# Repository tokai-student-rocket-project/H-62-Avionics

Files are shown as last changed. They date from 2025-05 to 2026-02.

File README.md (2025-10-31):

# H-62-Avionics

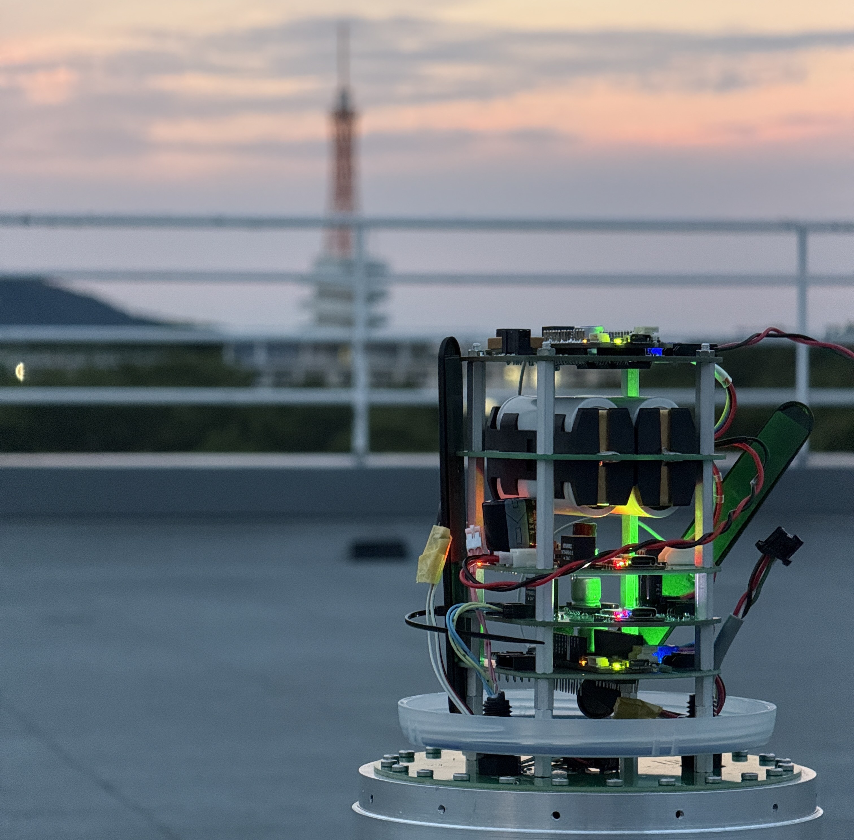
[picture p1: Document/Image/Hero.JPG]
Hero


H-62搭載計器　すばる1.3 | 2025年度 夏季 能代 NOGO

すばる1.2 の機能を引き継ぎつつ海打上げ実験用に改良を加えました

- 水密機能の搭載
- 基板径をΦ90に変更
- LYLYGO開発ボードを活用した地上局

## ドキュメント
- [PDR](./Document/PDR/Subaru1.3_PDR.pdf)
- [CDR](./Document/CDR/Subaru1.3_CDR.pdf)
- [報告書](./Document/Report/Report.md)

## ディレクトリ構成
### [Document](./Document/)
資料を格納するディレクトリ

### [KiCAD](./KiCAD/)
KiCADのプロジェクトファイルを格納するディレクトリ
- [Flight Module](./KiCAD/FlightModule/)
- [Battery Module](./KiCAD/BatteryModule/)
- [Power Module](./KiCAD/PowerControlModule/)
- [Battery Module](./KiCAD/18650BatteryModule/)
- [Sensing Module](./KiCAD/SensingModule/)
- [Valve Control Module](./KiCAD/ValveControlModule/)
- [Subaru Plate](./KiCAD/SubaruPlate/)

### [lib](./lib/)
ライブラリを格納するディレクトリ

Lib_ から始まるライブラリはラッパーライブラリとなっています

### [src](./src/)
ソースコードを格納するディレクトリ

**Flight** : 搭載計器のソースコード
- [Flight Module](./src/Flight/FlightModule/FlightModule.cpp)
- [Power Module](./src/Flight/PowerModule/PowerModule.cpp)
- [Sensing Module](./src/Flight/SensingModule/SensingModule.cpp)
- [Valve Control Module](./src/Flight/ValveControlModule/ValveControlModule.cpp)

**Ground** : 地上局のソースコード
- [Ground Flight Module](./src/Ground/CSV/FlightModule/FlightModule.cpp)
- [Ground Sensing Module](./src/Ground/CSV/SensingModule/SensingModule.cpp)
- [Sea Flight Module](./src/Ground/T-BEAM/FlightModule/FlightModule.cpp)
- [Teleplot Ground Flight Module](./src/Ground/Teleplot/FlightModule/FlightModule.cpp)
  - [Teleplot Layout](./src/Ground/Teleplot/FlightModule/teleplot_layout_FlightModule.json)

**LogDumper** : ログ読み出しのソースコード
- [Flight Module](./src/LogDumper/FlightModule/FlightModule.cpp)
- [Sensing Module](./src/LogDumper/SensingModule/SensingModule.cpp)

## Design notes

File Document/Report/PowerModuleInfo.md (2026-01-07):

# Power Module (すばる1.3)

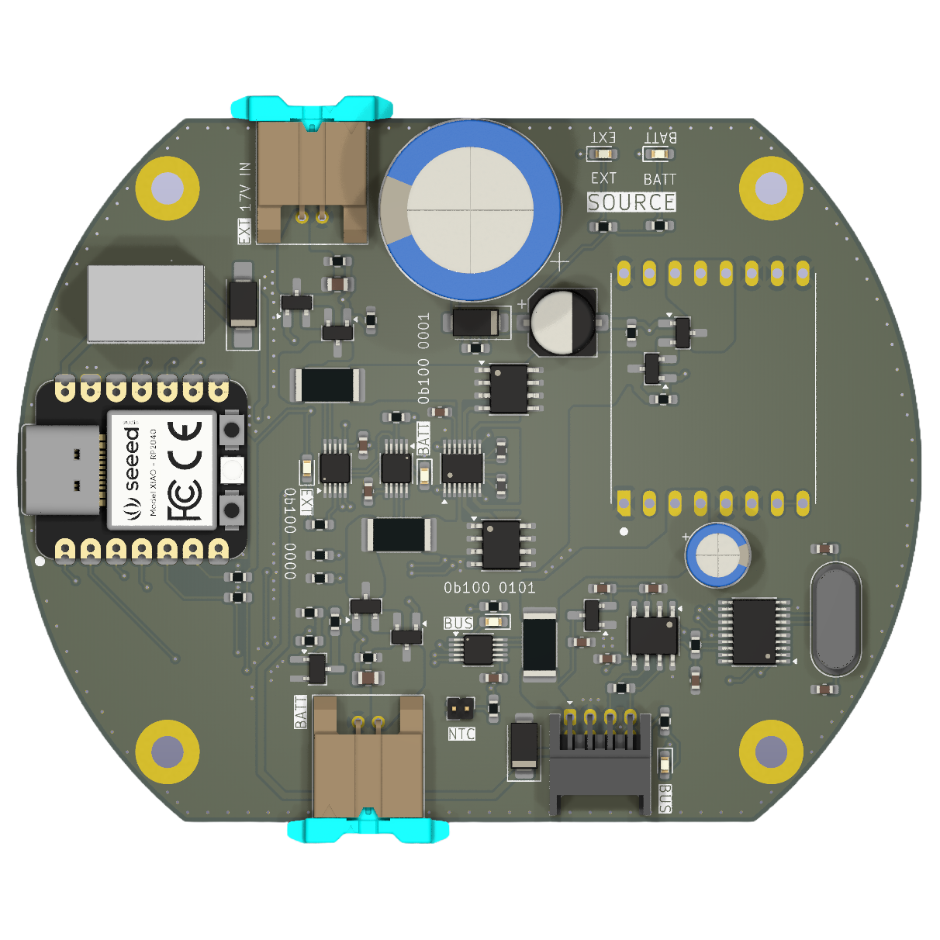
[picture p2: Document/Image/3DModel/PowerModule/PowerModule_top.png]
Hero


## 概要
ロケットの外部電源と内部電源を自動切換え機能を搭載しつつ，最大負荷5Aに対応した電源管理モジュールです．

## 主な構成部品
- **MCU**: `Seeed XIAO RP2040`
  - パワーモジュールを制御するマイコンです．
  - 実装されたフルカラーLEDを用いて内部電源の残量を表示可能
- **電流・電圧・電力モニター**: [`INA228`](https://www.digikey.jp/ja/products/detail/texas-instruments/INA228AIDGSR/13691042)
  - Adafruit社のモジュールを参考にし回路を構成
  - A0とA1ピンを用いてI2Cアドレスを変更可能な点が魅力的
- **電源制御IC**: [`LTC4353`](https://www.digikey.jp/ja/products/detail/analog-devices-inc/LTC4353IMS-PBF/3305800)
  - 2つの外付けMOSFETを制御し理想ダイオードOR回路を実装
  - MOSFETの選定には[`Si26DY`](https://www.digikey.jp/ja/products/detail/vishay-siliconix/SI4126DY-T1-GE3/1978841)がおすすめ（データシートの構成を参考）
- **DCDCコンバーター**: [`LTC3119`](https://strawberry-linux.com/catalog/items?code=13119)
  - 昇圧＋降圧に対応かつ最大負荷5A，さらに耐圧18Vと高スペックなICとなっている．
  - しかし，少し高価なICとなっている．
  - 代替品として，[SC8721](https://strawberry-linux.com/catalog/items?code=18721) という選択肢もあるが試すことができていないが1/4のコストは魅力的である．
- **ロードスイッチ**: [`AO3401AとAO3400A`]
  - Pch MOSFET の AO3401A をBack to back 接続し電流の逆流防止回路を構成
  - 秋月電子で販売終了したためピンコンパチか，代替品を探す必要有り

## 機能
### 電力モニター
3つの INA228 により，外部電源，内部電源，バス電源を監視することが可能となっている．
内部電源の監視はLiFePO4バッテリーの最小放電電圧を監視し，計測した電圧は内部電源遮断信号のトリガーとなっている．

### 電源切替
電源切替時の動作は電源をどのように接続したかとフライトモードの状態により変化する．
#### 外部電源入力時 
外部電源が入力されるとDCDCコンバーターを介して昇圧，もしくは降圧されバスへと出力される．
同時に，マイコンへ給電される．
この時，内部電源はロードスイッチのゲートが駆動しないため，遮断される．これにより，外部電源が接続されたとしてもバスを通じて各モジュールには電源投入されるが，内部電源は消費せずに運用することが可能となる．

詳しくは，回路を見ながらソースコードを参照すると理解しやすいはず．

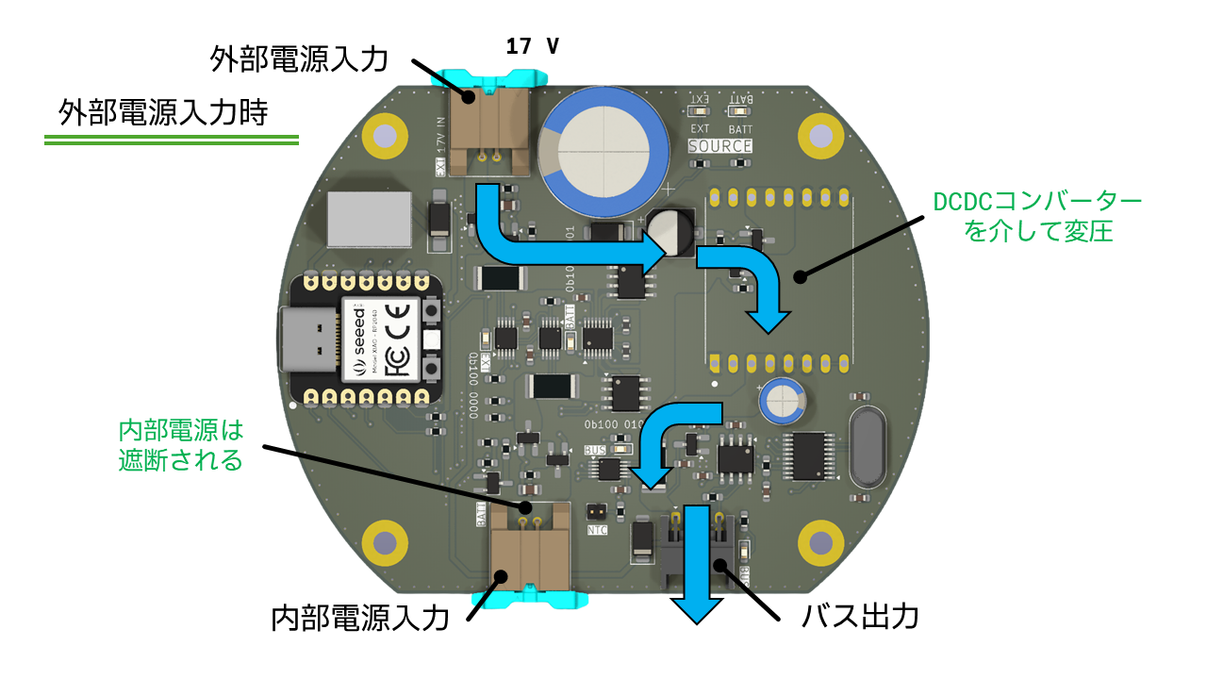
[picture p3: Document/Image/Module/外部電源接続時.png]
外部電源入力時


#### FlightMode変化時
Flight Mode が変化し READY_TO_FLY になると，内部電源が入力される．しかし，LTC4353 は高い電圧を優先するため外部電源（17 V）が入力されている間は内部電源（公称 12.8 V）の消費を抑えてくれる．

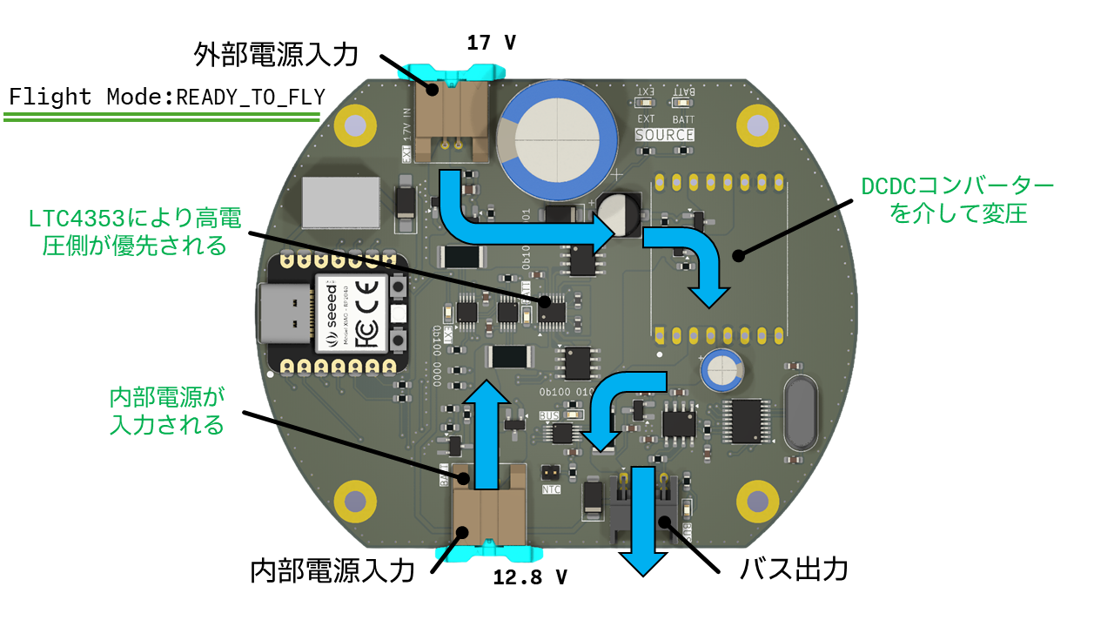
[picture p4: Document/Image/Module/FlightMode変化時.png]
FlightMode変化時


#### 外部電源遮断＋FlightMode変化時
FlihtMode が READY_TO_FLY 時に外部電源が遮断されると内部電源へと自動的に切り替わりDCDCコンバーターを介してバスに出力される．
内部電源がバスに出力された後は内部電源が 11V に降下すると内部電源が MOSFET により遮断される．これにより，LiFePO4バッテリーの過放電を防ぐ．
この過放電を防ぐための最小電圧は負荷をすべて接続し，LiFePO4バッテリーの放電グラフを作成し決定した．理論上では最小放電電圧はバッテリー1つあたり 2V （合計 2V x 4つ = 8V）だが安全を考慮し 11V に設定した．この値はプログラムで自由に調整可能となっている．

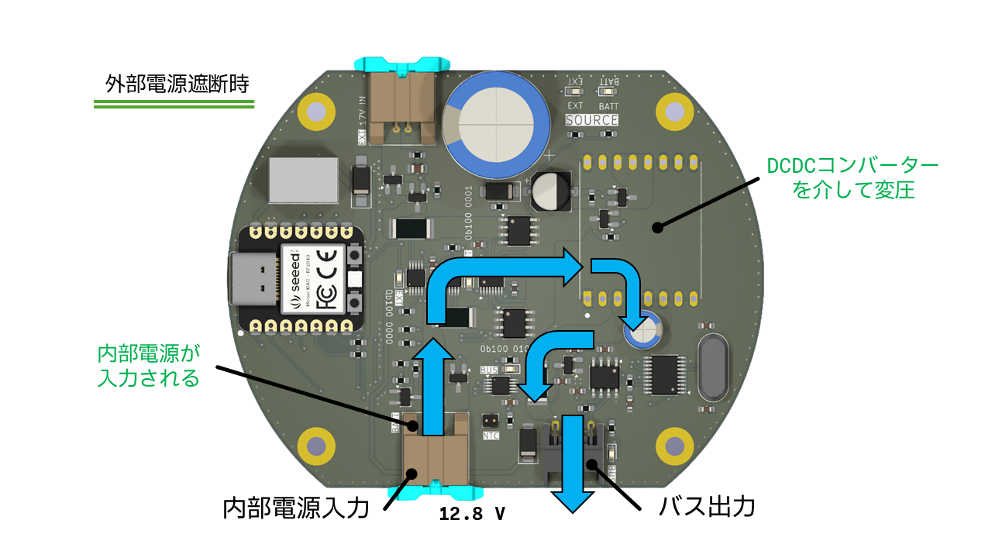
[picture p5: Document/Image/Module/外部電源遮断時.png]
外部電源遮断＋FlightMode変化時


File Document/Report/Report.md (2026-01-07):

# H-62 Avionics プロジェクト報告書

## 目次

- [H-62 Avionics プロジェクト報告書](#h-62-avionics-プロジェクト報告書)
  - [目次](#目次)
  - [1. 概要](#1-概要)
  - [2. プロジェクト構成](#2-プロジェクト構成)
    - [2.1. ディレクトリ構造](#21-ディレクトリ構造)
    - [2.2. 開発環境](#22-開発環境)
  - [3. システム構成](#3-システム構成)
    - [3.1. 全体像](#31-全体像)
    - [3.2. ハードウェア](#32-ハードウェア)
      - [3.2.1. モジュール](#321-モジュール)
      - [3.2.2. 地上局](#322-地上局)
    - [3.3. ソフトウェア](#33-ソフトウェア)
    - [3.3.1 機体内部通信: `CAN`](#331-機体内部通信-can)
    - [3.3.2 対地通信: `LoRa`](#332-対地通信-lora)
  - [4. ビルドと書き込み](#4-ビルドと書き込み)
    - [4.1. 準備](#41-準備)
    - [4.2. 手順](#42-手順)
      - [4.2.1. PlatformIO UIを使用する方法](#421-platformio-uiを使用する方法)
      - [4.2.2. PlatformIO CLIを使用する方法](#422-platformio-cliを使用する方法)
    - [4.3. 主要なビルド環境](#43-主要なビルド環境)
  - [5. Webダッシュボード (地上局)](#5-webダッシュボード-地上局)
    - [5.1. 手順](#51-手順)
    - [5.2. 機能](#52-機能)
  - [6. ログの読み出し](#6-ログの読み出し)
    - [6.2. ビルド環境](#62-ビルド環境)
    - [6.3. 手順](#63-手順)
  - [00. 添付資料](#00-添付資料)

---

## 1. 概要

本ドキュメントは、H-62に搭載される「すばる1.3」の設計、機能、および運用方法について記述したものである。将来の拡張やメンテナンスのための引き継ぎ資料として利用することを目的とする。

このシステムは、ロケットに搭載される複数の**モジュール**と、地上でデータを受信する**地上局**の2つの主要コンポーネントから構成される。

## 2. プロジェクト構成

このプロジェクトは、ハードウェア設計、ソースコード、ドキュメント、試験コードなど、開発に必要なすべての要素を単一のリポジトリで管理している。

### 2.1. ディレクトリ構造

プロジェクトの全体像を把握するために、主要なディレクトリの役割を以下に示す。

- `src/`: すべての組込みソフトウェアのソースコードが格納されている。
  - `Flight/`: ロケットに搭載する各モジュール（Flight, Power, Sensing, ValveControl）のコード。
  - `Ground/`: 地上局用のコード。Webサーバー機能を持つものも含まれる。
  - `LogDumper/`: メモリ（FeRAM）からログを読み出すためのコード。
  - `Experiment/`: 各種実験用のコード。
- `lib/`: モジュール間で共通して使用されるライブラリ。
- `KiCAD/`: 各モジュールの回路図、PCBレイアウトなど、ハードウェアの設計データ。
- `Document/`: データシート、ブロック図、本報告書などのドキュメント類。
- `test/`: 本プロジェクトで行った試験の結果。
- `data/`: 地上局のWebダッシュボードで使用するHTMLやCSSファイル。
- `platformio.ini`: プロジェクトのビルド構成、ライブラリ依存関係などを定義したファイル。

### 2.2. 開発環境

- **IDE**: Visual Studio Code
- **拡張機能**: PlatformIO
- **言語**: Arduino

プロジェクトのビルド環境やライブラリ依存関係は、ルートディレクトリの `platformio.ini` ファイルで管理されている。

platformio.ini ファイルの構成を簡単に示す。
```
[env:FlightModule] 
platform = atmelsam
board = mkrwan1310
framework = arduino
monitor_speed = 115200
build_src_filter = +<Flight/FlightModule/FlightModule.cpp>
lib_deps = 
	SPI
	Wire
	seeed-studio/CAN_BUS_Shield@^2.3.3
	hideakitai/TaskManager@^0.5.2
	frankboesing/FastCRC@^1.41
	adafruit/Adafruit BusIO@^1.16.1
	jchristensen/movingAvg@^2.3.1
	hideakitai/Filters@^0.1.2
	sparkfun/SparkFun u-blox GNSS Arduino Library@^2.2.27
	hideakitai/CRCx@^0.4.0
	hideakitai/MsgPacketizer@^0.5.3
	bblanchon/ArduinoJson@^7.2.1
	sandeepmistry/LoRa@^0.8.0
```

`[env:FlightModule]` : ビルド環境名 ([参考ページ](https://docs.platformio.org/en/stable/projectconf/sections/env/index.html#working-env-name))

`platform` : 使用したいボードのマイコンファミリー ([参考ページ](https://docs.platformio.org/en/stable/projectconf/sections/env/options/platform/platform.html))

`board` : 使用したいボード ([参考ページ](https://docs.platformio.org/en/stable/projectconf/sections/env/options/platform/board.html))

`framework` : フレームワークの設定 ([参考ページ](https://docs.platformio.org/en/stable/frameworks/index.html#frameworks))

`monitor_speed` : シリアルモニタのボーレート([参考ページ](https://docs.platformio.org/en/stable/projectconf/sections/env/options/monitor/monitor_speed.html))(ただし，VSCodeの拡張機能である[Serial Monitor](https://marketplace.visualstudio.com/items?itemName=ms-vscode.vscode-serial-monitor)を使う場合は特に関係ない)

`build_src_filter` : どのプログラムを書きこむのか指定 ([参考ページ](https://docs.platformio.org/en/stable/projectconf/sections/env/options/build/build_src_filter.html))

`lib_deps` : 依存しているライブラリを指定 ([参考ページ](https://docs.platformio.org/en/stable/projectconf/sections/env/options/library/lib_deps.html))

## 3. システム構成

### 3.1. 全体像

システム全体の電源系統と接続の概要を以下に示す。

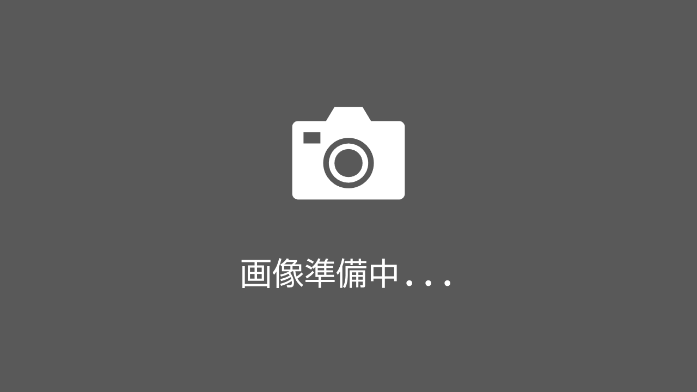
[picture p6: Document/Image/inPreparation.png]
  

### 3.2. ハードウェア

#### 3.2.1. モジュール

- **FlightModule**: GPS、IMUなどを搭載し、分離制御とLoRaによるテレメトリー送信を行うモジュール。
  - **MCU**: `Arduino MKR WAN 1310`

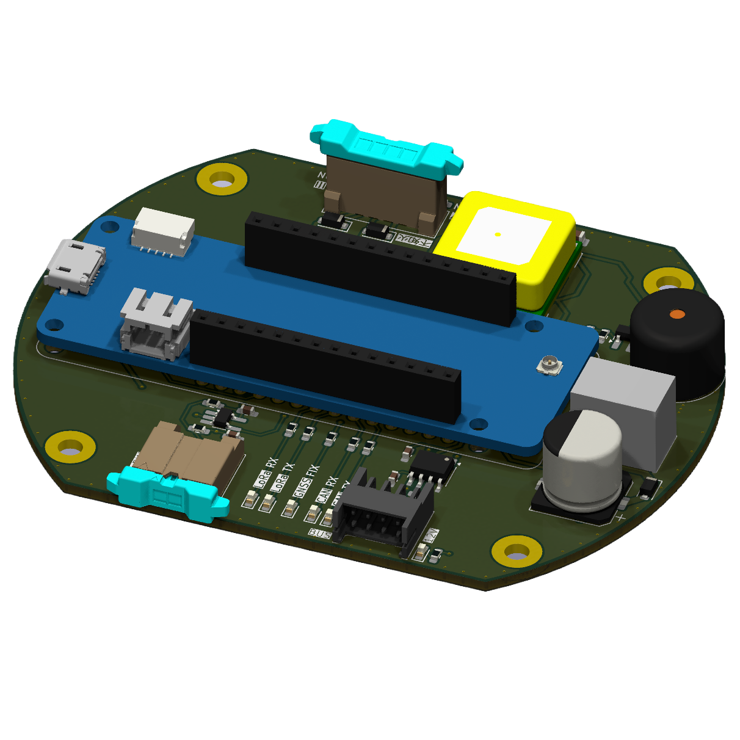
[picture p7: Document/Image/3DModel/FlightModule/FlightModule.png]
Flight Module
  

- **PowerModule**: バッテリーから各モジュールへ電源を供給・管理するモジュール。
  - **MCU**: `Seeed XIAO RP2040`
  - **CAN**: `MCP2515 & MCP2562`
    - MCP2515とマイコンをSPI通信で接続しCAN通信を行う
    - MCP2562によりCAN通信の物理層を実装する
    - 必要に応じて終端抵抗(120Ω)が必要
  - **Power Management IC**: [`LTC4353`](https://www.digikey.jp/ja/products/detail/analog-devices-inc/LTC4353IMS-PBF/3305800)
    - 外付けのMOSFETを制御し理想ダイオードをの機能を実装する
    - MOSFETの選定には[`Si26DY`](https://www.digikey.jp/ja/products/detail/vishay-siliconix/SI4126DY-T1-GE3/1978841)がおすすめ
    - パッケージは複数あるがLTC4353IMS`#PBF`にすることで「足」が生えているためはんだ不良を検査しやすい
  - **DCDC Convertor**:[`LTC3119`](https://strawberry-linux.com/catalog/items?code=13119)
    - 最大負荷5Aに対応し18Vまで対応しているため便利で扱いやすい
    - ただし価格がお高め
  - [CAD | KiCAD はこちら](../../KiCAD/PowerControlModule/)

> [!NOTE]
> Power Module の詳細は [こちら](./PowerModuleInfo.md)

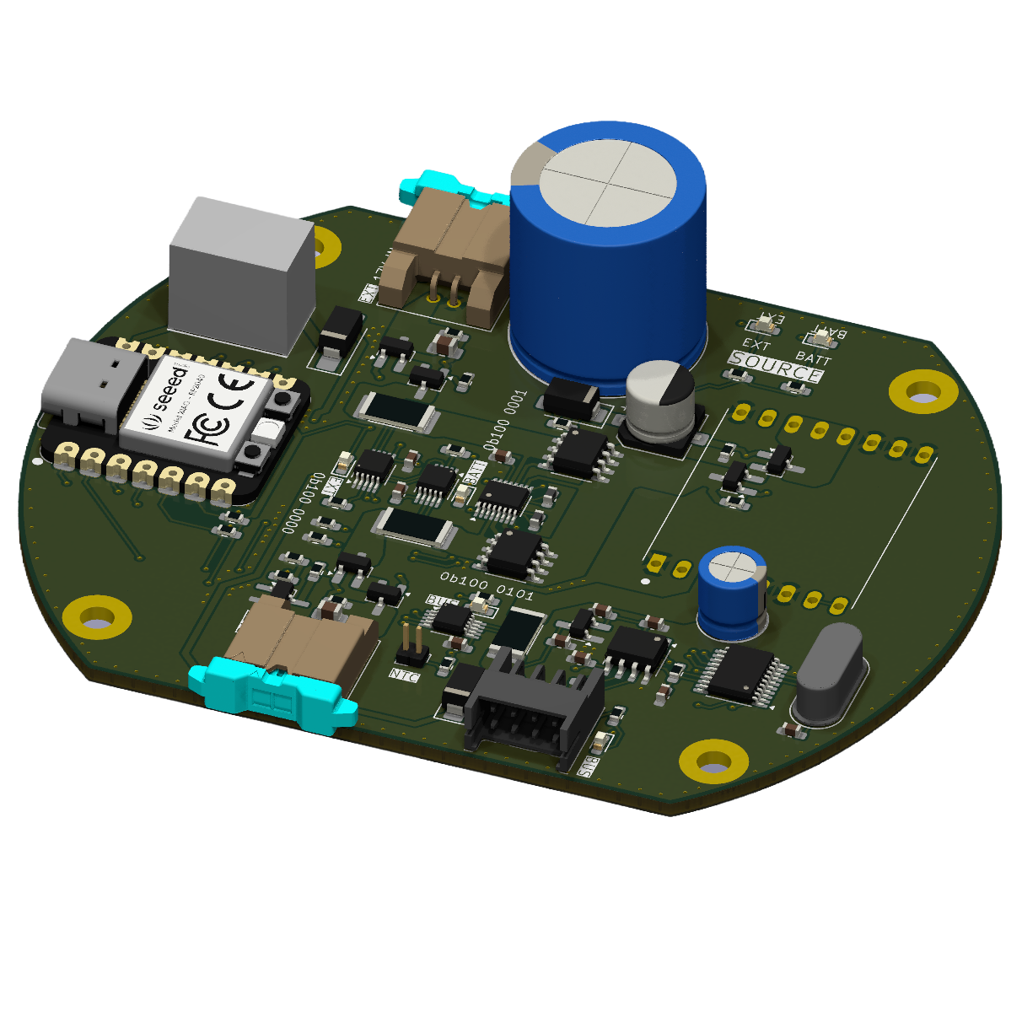
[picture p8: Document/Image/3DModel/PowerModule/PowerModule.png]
Power Module
  

- **18650 Battery Module**: バッテリー固定用のモジュール。

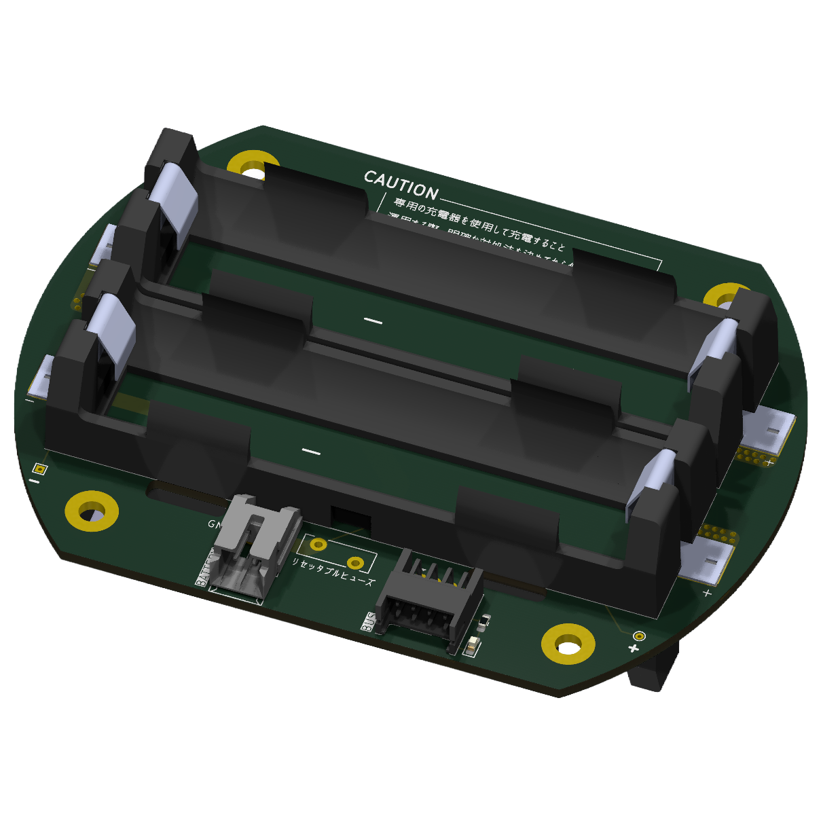
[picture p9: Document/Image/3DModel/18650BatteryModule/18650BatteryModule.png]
Power Module
  

- **SensingModule**: 圧力センサーなどを搭載し、詳細な環境データを取得する。
  - **MCU**: `Arduino MKR WAN 1310`
  - **CAN**: `MCP2515 & MCP2562`
    - MCP2515とマイコンをSPI通信で接続しCAN通信を行う
    - MCP2562によりCAN通信の物理層を実装する
    - 必要に応じて終端抵抗(120Ω)が必要
  - **Pressure Sensor**: `LPS28DFW`
    - 気圧と温度センサが一つのパッケージにまとまっている
    - 小型かつ防水（Oリングなどで工夫する必要有）なため使いやすい
  - **IMU**: `BNO055`
    - 入手性が良い

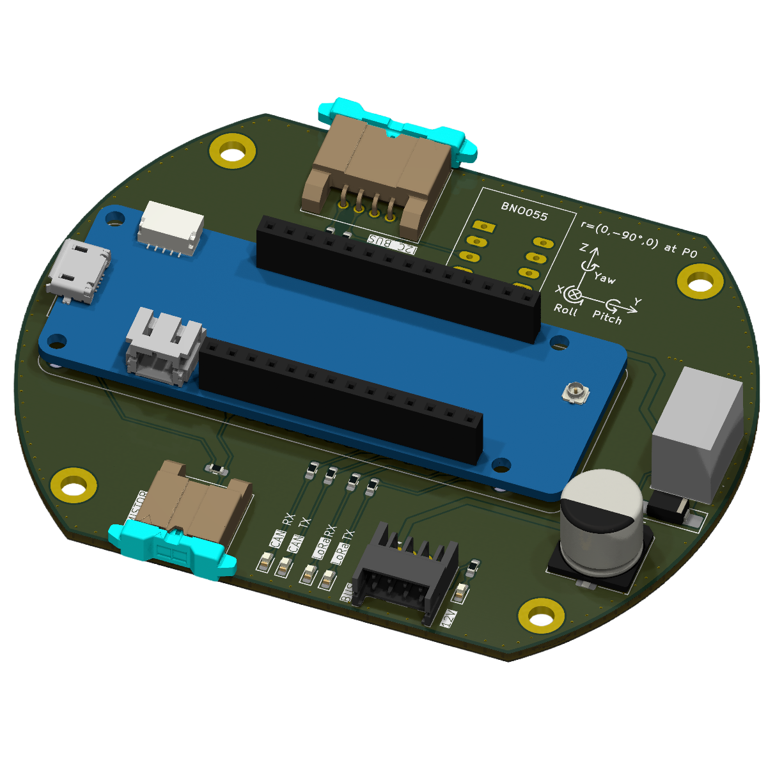
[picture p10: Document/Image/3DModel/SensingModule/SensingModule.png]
Sensing Module
  

- **ValveControlModule**: バルブを制御するためのモジュール。
  - **MCU**: `Seeed XIAO RP2040`
  - **CAN**: `MCP2515 & MCP2562`
    - MCP2515とマイコンをSPI通信で接続しCAN通信を行う
    - MCP2562によりCAN通信の物理層を実装する
    - 必要に応じて終端抵抗(120Ω)が必要
  - **RS485**: `MAX3485`
    - 3.3V駆動のRS485/RS422トランシーバー

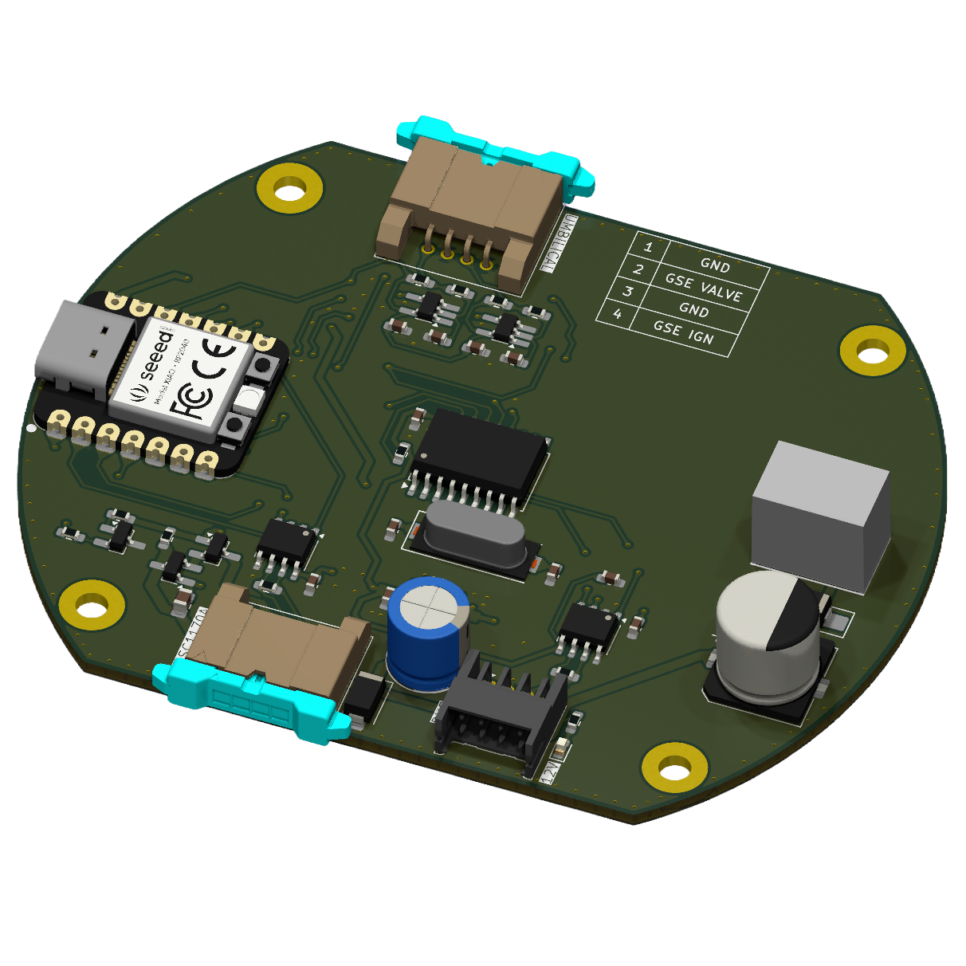
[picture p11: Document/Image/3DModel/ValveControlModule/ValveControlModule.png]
ValveControlModule
  

#### 3.2.2. 地上局

地上でフライトモジュール、センシングモジュールからのデータを受信し、可視化する。

- **LILYGO T-Beam**: LoRaで受信したデータをOLEDに表示すると同時に、Wi-Fi経由でWebダッシュボードにリアルタイム表示する。([商品ページ](https://lilygo.cc/products/t-beam?srsltid=AfmBOop5EgjoO9m0INnMgOT41JxyNSMiZya5QNhKdbZDgODq3Bx6JJTY))
  - **MCU**: `ESP32`
  - **ディスプレイ**: `SSD1306` OLEDディスプレイ
  - **GPS**: `NEO-6M`
  - **PMU**: `AXP2101`
  - **Wireless protocol**: `Wi-Fi + Bluetooth 4.2`

  ValveControlModule

### 3.3. ソフトウェア

### 3.3.1 機体内部通信: `CAN`

  機体内部の通信にはCAN通信を採用している．これは差動信号であるためノイズ耐性が高いこととパケット構造（データフレームと呼ぶ）が決まっているため扱いやすい良い点が挙げられる．

  CAN周りのソースコードは[`Lib_CAN.hpp`](/lib/Lib_CAN/Lib_CAN.hpp), [`Lib_CAN.cpp`](/lib/Lib_CAN/Lib_CAN.cpp)に記述されている．そして，CANのIDは[`Lib_Var.hpp`](/lib/Lib_Var/Lib_Var.hpp)に定義されている．

  CAN IDのとれる値の範囲は**標準フォーマット**を使用している．なお，拡張フォーマットを使用することも可能だがそこまでの大規模システムを構築する必要はないと考える．

  | フォーマット     | ビット長 | 10進数の範囲  | 16進数の範囲          |
  | ---------------- | -------- | ------------- | --------------------- |
  | 標準フォーマット | 11ビット | 0~2,047       | 0x000~0x7FF           |
  | 拡張フォーマット | 29ビット | 0~536,870,911 | 0x00000000~0x1FFFFFFF |

  以下に，CANのデータ構造をまとめる．

  **FLIGHT_DATA (ID: 0x00)**

  `役割`：フライトデータ送信, `データ長`: 7 Byte
  | フィールド名 | オフセット (Byte) | サイズ (Byte) | データ型 | 説明                                    |
  | ------------ | ----------------- | ------------- | -------- | --------------------------------------- |
  | flightMode   | 0                 | 1             | uint8_t  | 現在のフライトモード                    |
  | flightTime   | 1                 | 4             | uint32_t | 飛行時間 [ ms ]                         |
  | doLogging    | 5                 | 1             | bool     | ロギング実行フラグ( 1: True, 0: False ) |
  | ident        | 6                 | 1             | char     | 識別子(A, B など)                       |

  **TRAJECTORY_DATA (ID: 0x01)**

  `役割`: 軌道データ送信, `データ長`: 5 Byte
  | フィールド名 | オフセット (Byte) | サイズ (Byte) | データ型 | 説明       |
  | ------------ | ----------------- | ------------- | -------- | ---------- |
  | isFalling    | 0                 | 1             | bool     | 降下判定   |
  | altitude     | 1                 | 4             | float    | 高度 [ m ] |

  **GSE_SIGNAL (ID: 0x02)**

  `役割`: イグニッションの実行判定, `データ長`: 1 Byte
  | フィールド名 | オフセット (Byte) | サイズ (Byte) | データ型 | 説明                                       |
  | ------------ | ----------------- | ------------- | -------- | ------------------------------------------ |
  | isIgnition   | 0                 | 1             | bool     | イグニッション実行フラグ ( 1: On, 0: Off ) |

  **VALVE_MODE (ID: 0x03)**

  `役割`: バルブモードの実行判定, `データ長`: 1 Byte
  | フィールド名 | オフセット (Byte) | サイズ (Byte) | データ型 | 説明                                     |
  | ------------ | ----------------- | ------------- | -------- | ---------------------------------------- |
  | isLaunchMode | 0                 | 1             | bool     | ローンチモード ( 1: Launch, 0: Waiting ) |

  **VALVE_DATA_PART1 (ID: 0x10B)**

  `役割`: サーボモーターからの情報, `データ長`: 8 Byte
  | フィールド名     | オフセット (Byte) | サイズ (Byte) | データ型 | 説明                                    |
  | ---------------- | ----------------- | ------------- | -------- | --------------------------------------- |
  | motorTemperature | 0                 | 2             | int16_t  | サーボモーターの温度 [ *C ]             |
  | mcuTemperature   | 2                 | 2             | int16_t  | サーボモーター制御マイコンの温度 [ *C ] |
  | current          | 4                 | 2             | int16_t  | サーボモーターに流れた電流 [ A ]        |
  | inputVoltage     | 6                 | 2             | uint16_t | サーボモーターへの入力電圧 [ V ]        |

  **VALVE_DATA_PART2 (ID: 0x10C)**

  `役割`: サーボモーターからの情報, `データ長`: 6 Byte
  | フィールド名           | オフセット (Byte) | サイズ (Byte) | データ型 | 説明                                     |
  | ---------------------- | ----------------- | ------------- | -------- | ---------------------------------------- |
  | currentPosition        | 0                 | 2             | int16_t  | サーボモーターの現在角度 [ deg ]         |
  | currentDesiredPosition | 2                 | 2             | int16_t  | サーボモーター制御マイコンの温度 [ deg ] |
  | currentVelocity        | 4                 | 2             | int16_t  | サーボモーターに流れた電流 [ deg/s ]     |

  **VALVE_DATA_PART3 (ID: 0x10D)**

  `役割`: サーボモーターからの情報, `データ長`: 8 Byte
  | フィールド名     | オフセット (Byte) | サイズ (Byte) | データ型 | 説明                                    |
  | ---------------- | ----------------- | ------------- | -------- | --------------------------------------- |
  | motorTemperature | 0                 | 2             | int16_t  | サーボモーターの温度 [ *C ]             |
  | mcuTemperature   | 2                 | 2             | int16_t  | サーボモーター制御マイコンの温度 [ *C ] |
  | current          | 4                 | 2             | int16_t  | サーボモーターに流れた電流 [ A ]        |
  | inputVoltage     | 6                 | 2             | uint16_t | サーボモーターへの入力電圧 [ V ]        |

  **VALVE_DATA_PART4 (ID: 0x10E)**

  `役割`: サーボモーターからの情報, `データ長`: 6 Byte
  | フィールド名           | オフセット (Byte) | サイズ (Byte) | データ型 | 説明                                     |
  | ---------------------- | ----------------- | ------------- | -------- | ---------------------------------------- |
  | currentPosition        | 0                 | 2             | int16_t  | サーボモーターの現在角度 [ deg ]         |
  | currentDesiredPosition | 2                 | 2             | int16_t  | サーボモーター制御マイコンの温度 [ deg ] |
  | currentVelocity        | 4                 | 2             | int16_t  | サーボモーターに流れた電流 [ deg/s ]     |

  **MONITOR_BUS (ID: 0x10F)**

  `役割`: バスの電力監視, `データ長`: 8 Byte
  | フィールド名       | オフセット (Byte) | サイズ (Byte) | データ型 | 説明                  |
  | ------------------ | ----------------- | ------------- | -------- | --------------------- |
  | busVoltage_int     | 0                 | 2             | int16_t  | CANバス電圧監視 [ V ] |
  | busCurrent_int     | 2                 | 2             | int16_t  | CANバス電流 [ A ]     |
  | busPower_int       | 4                 | 2             | int16_t  | CANバス電力 [ W ]     |
  | busTemperature_int | 6                 | 2             | int16_t  | ICの温度 [ *C ]       |

  **MONITOR_BATTERY (ID: 0x110)**

  `役割`: バッテリーの電力監視, `データ長`: 8 Byte
  | フィールド名           | オフセット (Byte) | サイズ (Byte) | データ型 | 説明                     |
  | ---------------------- | ----------------- | ------------- | -------- | ------------------------ |
  | batteryVoltage_int     | 0                 | 2             | int16_t  | バッテリー電圧監視 [ V ] |
  | batteryCurrent_int     | 2                 | 2             | int16_t  | バッテリー電流 [ A ]     |
  | batteryPower_int       | 4                 | 2             | int16_t  | バッテリー電力 [ W ]     |
  | batteryTemperature_int | 6                 | 2             | int16_t  | ICの温度 [ *C ]          |

  **MONITOR_EXTERNAL (ID: 0x111)**

  `役割`: 外部給電の電力監視, `データ長`: 8 Byte
  | フィールド名            | オフセット (Byte) | サイズ (Byte) | データ型 | 説明                     |
  | ----------------------- | ----------------- | ------------- | -------- | ------------------------ |
  | externalVoltage_int     | 0                 | 2             | int16_t  | 外部給電の電圧監視 [ V ] |
  | externalCurrent_int     | 2                 | 2             | int16_t  | 外部給電の電流 [ A ]     |
  | externalPower_int       | 4                 | 2             | int16_t  | 外部給電の電力 [ W ]     |
  | externalTemperature_int | 6                 | 2             | int16_t  | ICの温度 [ *C ]          |

### 3.3.2 対地通信: `LoRa`
  - [`hideakitai/MsgPacketizer`](https://github.com/hideakitai/MsgPacketizer) ライブラリを利用したカスタムバイナリ形式
  - **テレメトリーパケット (すばる -> 地上局)**: 識別子 `0x0A`
  - **コマンドパケット (地上局 -> すばる)**: 識別子 `0xF1` ~ `0xF3`

## 4. ビルドと書き込み

### 4.1. 準備

1. [Visual Studio Code](https://code.visualstudio.com/) をインストールする。
2. VSCodeの拡張機能パネルから `PlatformIO IDE` をインストールする。
3. 本プロジェクトをVSCodeで開くと、PlatformIOが必要なライブラリ (`platformio.ini` の `lib_deps`) を自動的にインストールする。

### 4.2. 手順

ビルドと書き込みは、VSCodeのPlatformIO UI、またはコマンドライン(CLI)から実行できる。

#### 4.2.1. PlatformIO UIを使用する方法

1. VSCodeの左側にあるPlatformIOアイコン (エイリアンの頭のようなアイコン) をクリックする。
2. `Project Tasks` の中から、対象の環境 (`env:***`) を見つける。
3. `Build` をクリックするとコンパイルが実行される。
4. `Upload` をクリックすると、接続されているデバイスにプログラムが書き込まれる。
5. `Monitor` をクリックすると、シリアルモニターが起動する。

#### 4.2.2. PlatformIO CLIを使用する方法

ターミナルから以下のコマンドを実行する。`-e` の後に対象の環境名を指定する。

```bash
# ビルドのみ
pio run -e <環境名>

# ビルドして書き込む
pio run -t upload -e <環境名>

# シリアルモニターを起動
pio device monitor -e <環境名>
```

### 4.3. 主要なビルド環境

`platformio.ini` には多数の環境が定義されているが、主に以下の環境を使用する。

| 用途 | 環境名 (`env:***`) | ボード | ソースコード |
| :--- | :--- | :--- | :--- |
| **フライトモジュール** | `FlightModule` | `mkrwan1310` | `src/Flight/FlightModule/` |
| **センシングモジュール** | `SensingModule` | `mkrwan1310` | `src/Flight/SensingModule/` |
| **パワーモジュール** | `PowerModule` | `seeed-xiao-rp2040` | `src/Flight/PowerModule/` |
| **バルブコントロールモジュール** | `ValveControlModule` | `seeed-xiao-rp2040` | `src/Flight/ValveControlModule/` |
| **地上局 (Webサーバー付き)** | `CSVGroundFlightModule`  | `esp32dev` | `src/Ground/CSV/FlightModule/` |
| **地上局** | `CSVGroundSensingModule` | `esp32dev` | `src/Ground/CSV/SensingModule/` |
| **地上局 (船回収隊)** | `SeaFlightModule` | `esp32dev` | `src/Ground/T-BEAM/FlightModule/` |
| **地上局（点火点）** | `TeleplotFlightModule` | `mkrwan1310` | `src/Ground/Teleplot/FlightModule/FlightModule.cpp` |

## 5. Webダッシュボード (地上局)

地上局 (Webサーバー付き) (`CSVGroundFlightModule`) は、受信したデータをリアルタイムで表示するWebダッシュボード機能を持つ。

### 5.1. 手順

1. `src/Ground/CSV/FlightModule/FlightModule.cpp` のWi-Fi設定を自身の環境に合わせて変更する。
   ```cpp
   const char* ssid = "YOUR_WIFI_SSID";
   const char* password = "YOUR_WIFI_PASSWORD";
   ```
2. 地上局をビルドし、ESP32に書き込む。
3. シリアルモニターを起動し、Wi-Fi接続後に表示されるIPアドレスを確認する。
4. PCやスマートフォンのブラウザでそのIPアドレスにアクセスする。

### 5.2. 機能

- **リアルタイム更新**: JavaScript (AJAX) を利用し、ページ全体をリロードすることなく、データ部分のみを非同期で更新する。下記は、デモプログラムを動作させた様子である。

telemetryMonitor

## 6. ログの読み出し

ログを読み出す際は，ログダンパー(LogDumoer)というビルド環境をマイコンに書き込む。

### 6.2. ビルド環境

| 用途 | 環境名 (`env:***`) | ボード | ソースコード |
| :--- | :--- | :--- | :--- |
| **フライトモジュール** | `LogDumper_FlightModule` | `mkrwan1310` | `src/LogDumper/FlightModule/FlightModule.cpp` |
| **センシングモジュール** | `LogDumperSensingModule` | `mkrwan1310` | `src/LogDumper/SensingModule/SensingModule.cpp` |

### 6.3. 手順

1. VSCodeの左側にあるPlatformIOアイコン (エイリアンの頭のようなアイコン) をクリックする。
2. `Project Tasks` の中から、対象の環境 (`env:***`) を見つける。
3. `Build` をクリックするとコンパイルが実行される。
4. `Upload` をクリックすると、接続されているデバイスにプログラムが書き込まれる。
5. TeraTermを開き`シリアル`を選択し，任意のCOMポートを選択する。
6. `OK`をクリックするとログ読み出しが開始される。(TeraTermで自動ログ保存機能を有効にしておくと便利 [参考ページ](https://www.reseau.co.jp/blog/archives/44))

## 00. 添付資料

- 各種電子部品のデータシートは `Document/Datasheet/` に格納されている。
- システムのブロック図などは `Document/BlockDiagram/` に格納されている。
- ハードウェアの3Dモデルや基板写真は `Document/Image/` に格納されている。

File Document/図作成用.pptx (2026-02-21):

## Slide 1

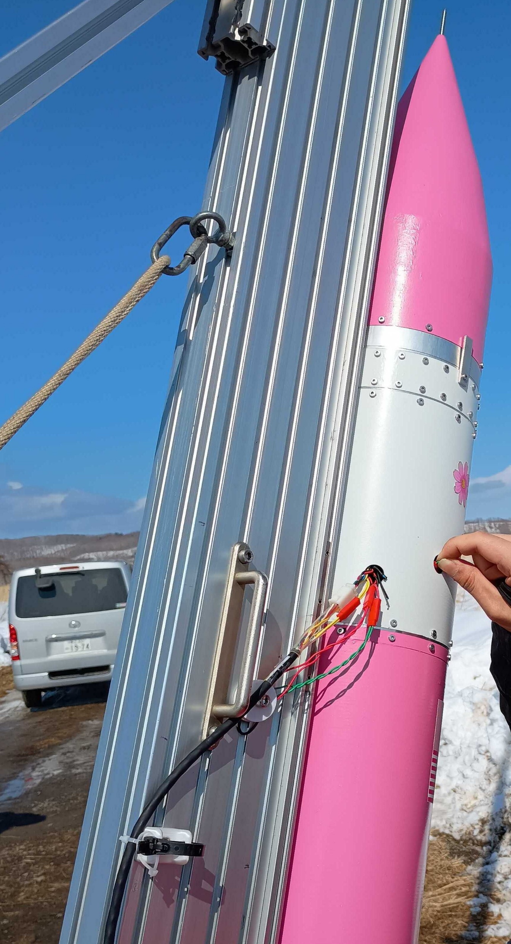
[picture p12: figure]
衣類, 男, 女性, 立つ が含まれている画像 AI によって生成されたコンテンツは間違っている可能性があります。

アンビリカルケーブル

フライトピン

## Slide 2

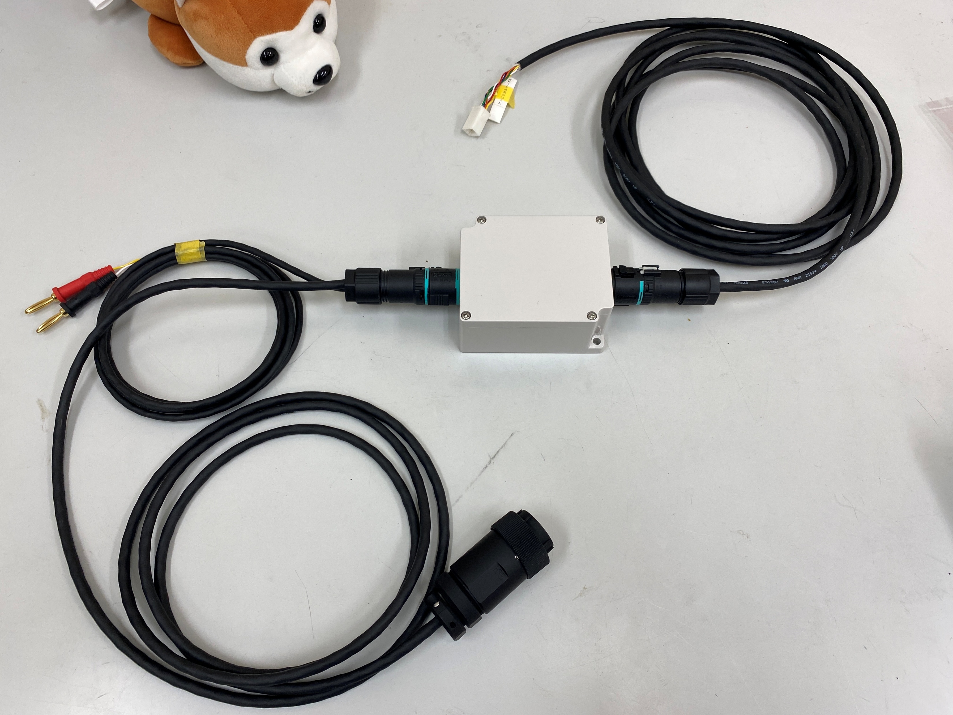
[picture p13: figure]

DF1Bシリーズ
中継コネクタ

機体側へ

安定化電源側へ

サテライトコントローラー側へ

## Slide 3

外部電源入力

グラフィカル ユーザー インターフェイス が含まれている画像 AI 生成コンテンツは誤りを含む可能性があります。

17 V

外部電源入力時

DCDCコンバーターを介して変圧

内部電源は
遮断される

内部電源入力

バス出力

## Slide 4

外部電源入力

17 V

Flight Mode:READY_TO_FLY

LTC4353により高電圧側が優先される

DCDCコンバーターを介して変圧

内部電源が入力される

内部電源入力

12.8 V

バス出力

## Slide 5

外部電源遮断時

DCDCコンバーターを介して変圧

内部電源が入力される

内部電源入力

12.8 V

バス出力

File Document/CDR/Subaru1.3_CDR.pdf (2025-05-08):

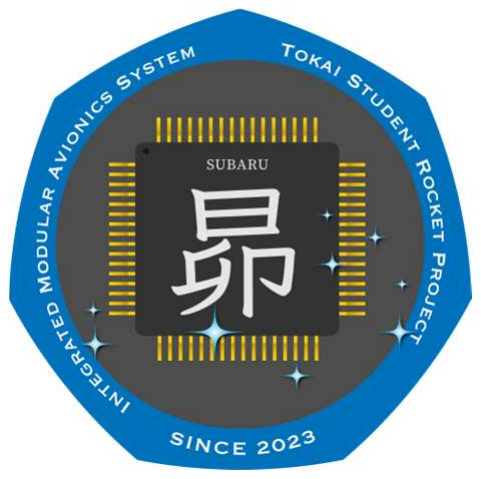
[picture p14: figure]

©Tokai Student Rocket Project

目次

# 1.主な仕様 2.他班との連携 3.懸念事項

## CDR

©Tokai Student Rocket Project

目次

# 1.主な仕様 2.他班との連携 3.懸念事項

## CDR

## 1. 主な仕様 Flight Module

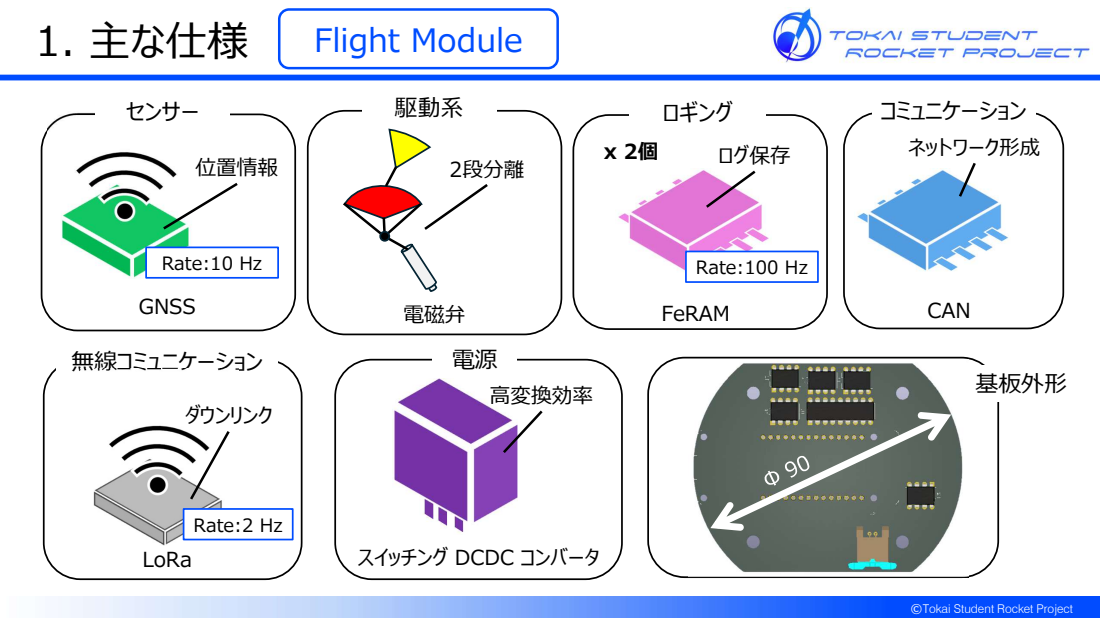
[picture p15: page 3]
GNSS; センサー; 位置情報; CAN; コミュニケーション ネットワーク形成; FeRAM; ログ保存; ロギング; 無線コミュニケーション; ダウンリンク; LoRa; 基板外形; 高変換効率; 電磁弁; 駆動系; 2段分離; Rate:10 Hz; Rate:100 Hz; Rate:2 Hz

スイッチング DCDC コンバータ

©Tokai Student Rocket Project

# 1. 主な仕様

## Sensing Module

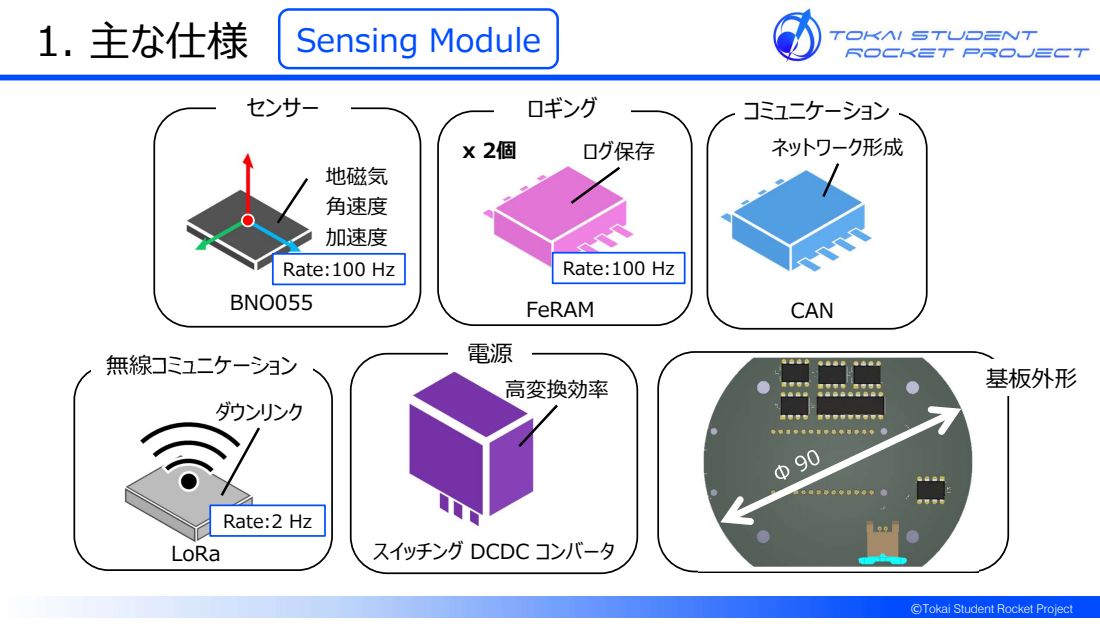
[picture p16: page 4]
センサー; 角速度; BNO055; 加速度; 地磁気; 無線コミュニケーション; ダウンリンク; LoRa; 基板外形; CAN; コミュニケーション ネットワーク形成; FeRAM; ログ保存; ロギング; 高変換効率; Rate:100 Hz; Rate:2 Hz

スイッチング DCDC コンバータ

©Tokai Student Rocket Project

# 1. 主な仕様

## Power Module

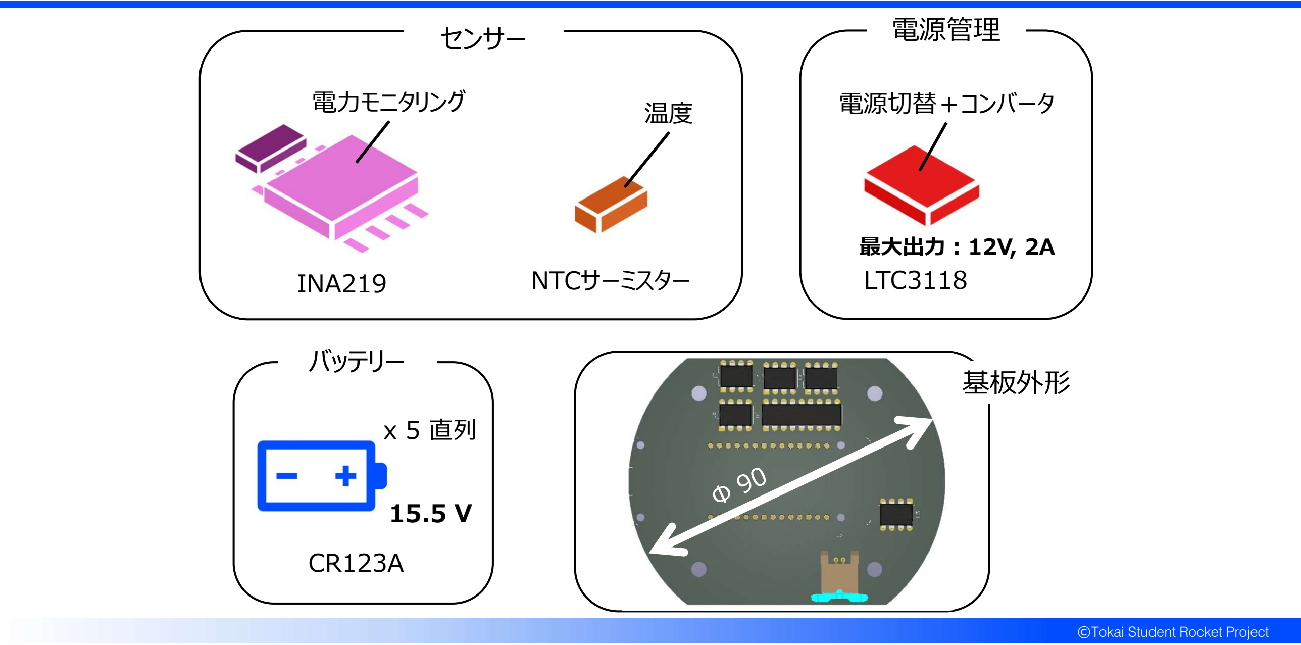
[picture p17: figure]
©Tokai Student Rocket Project; 基板外形 バッテリー; 電源管理; LTC3118; 電源切替＋コンバータ; センサー; 電力モニタリング; INA219; NTCサーミスター; 最大出力:12V, 2A

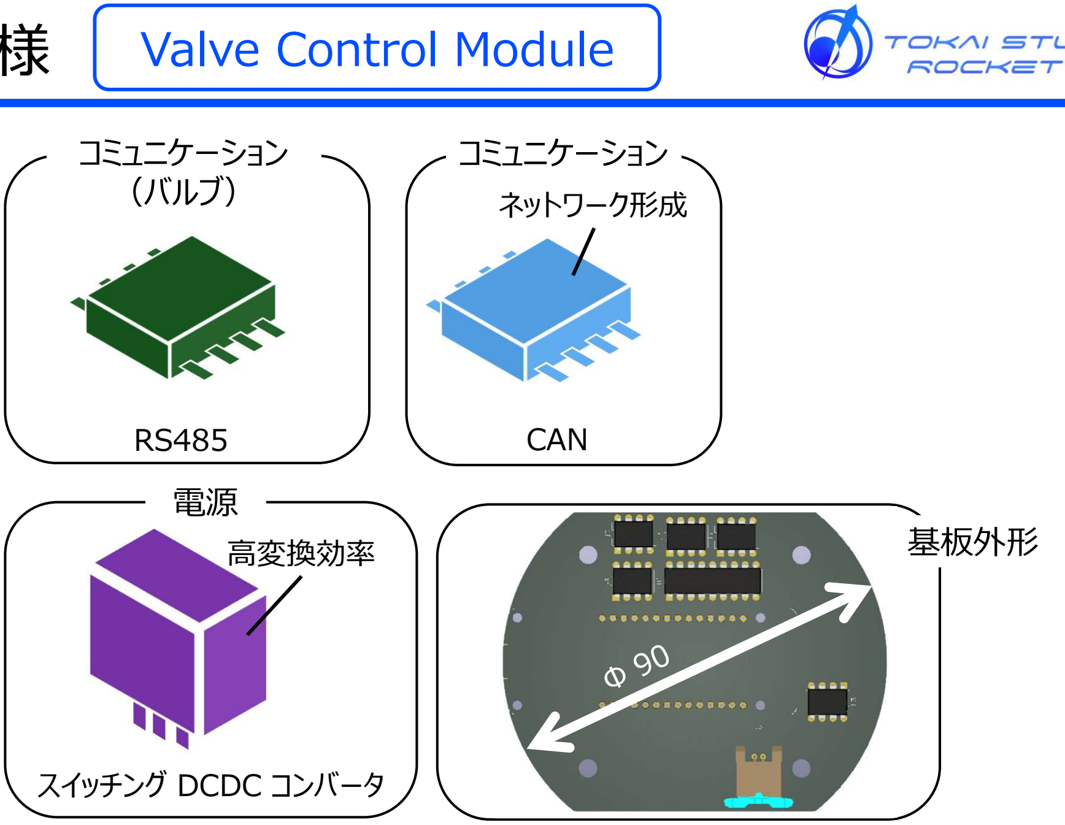
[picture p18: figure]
基板外形; CAN; コミュニケーション ネットワーク形成; コミュニケーション （バルブ）; スイッチング DCDC コンバータ; 高変換効率; Valve Control Module

©Tokai Student Rocket Project

# 1. 主な仕様

# 1. 主な仕様

## Subaru Plate

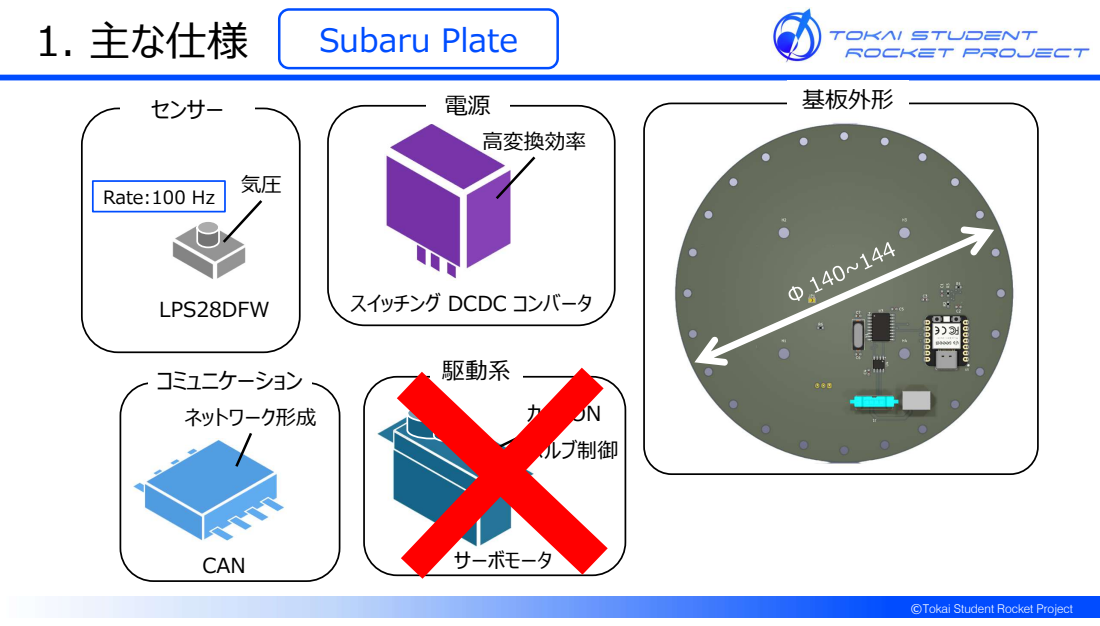
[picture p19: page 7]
基板外形; センサー; LPS28DFW; スイッチング DCDC コンバータ; 高変換効率; CAN; コミュニケーション ネットワーク形成; 駆動系; カメラON バルブ制御; サーボモータ; Rate:100 Hz

©Tokai Student Rocket Project

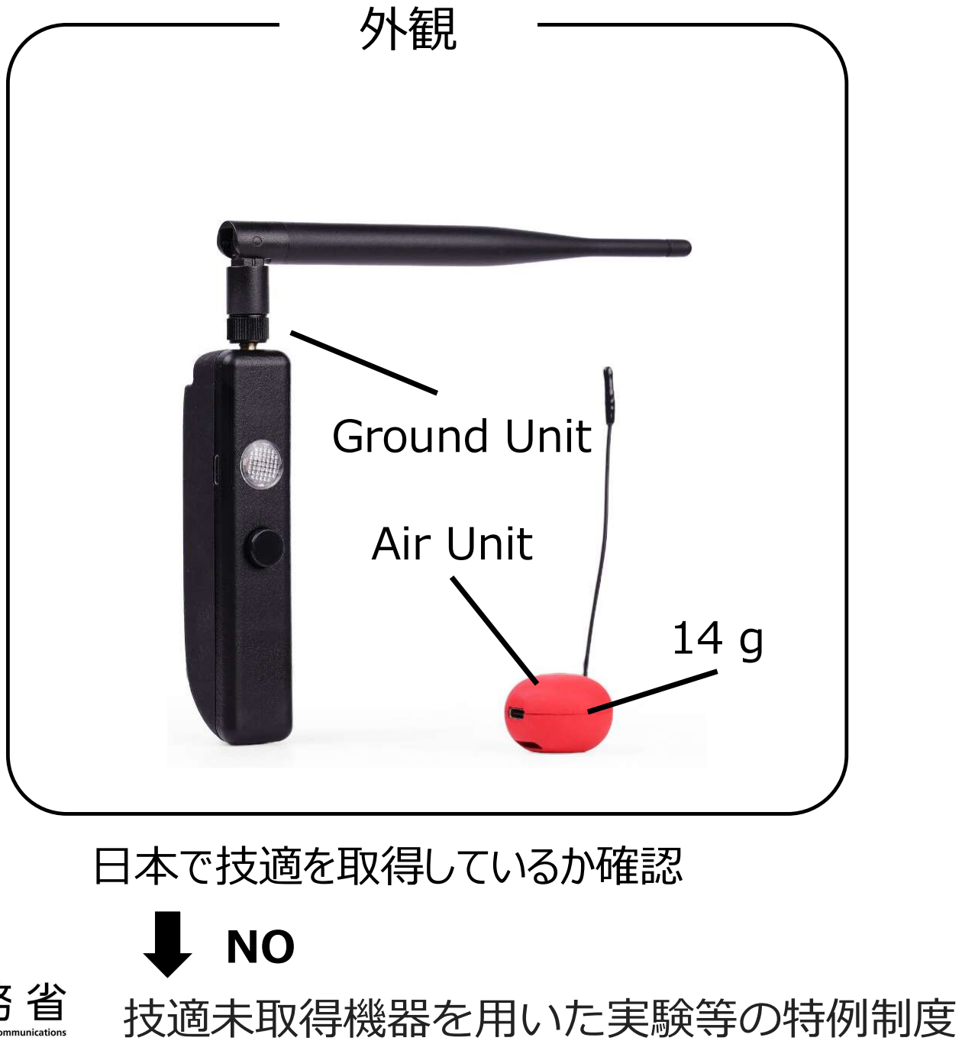
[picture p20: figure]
Air Unit; Ground Unit; 日本で技適を取得しているか確認; 技適未取得機器を用いた実験等の特例制度

©Tokai Student Rocket Project

## 1. 主な仕様 LoKo GPS Tracker

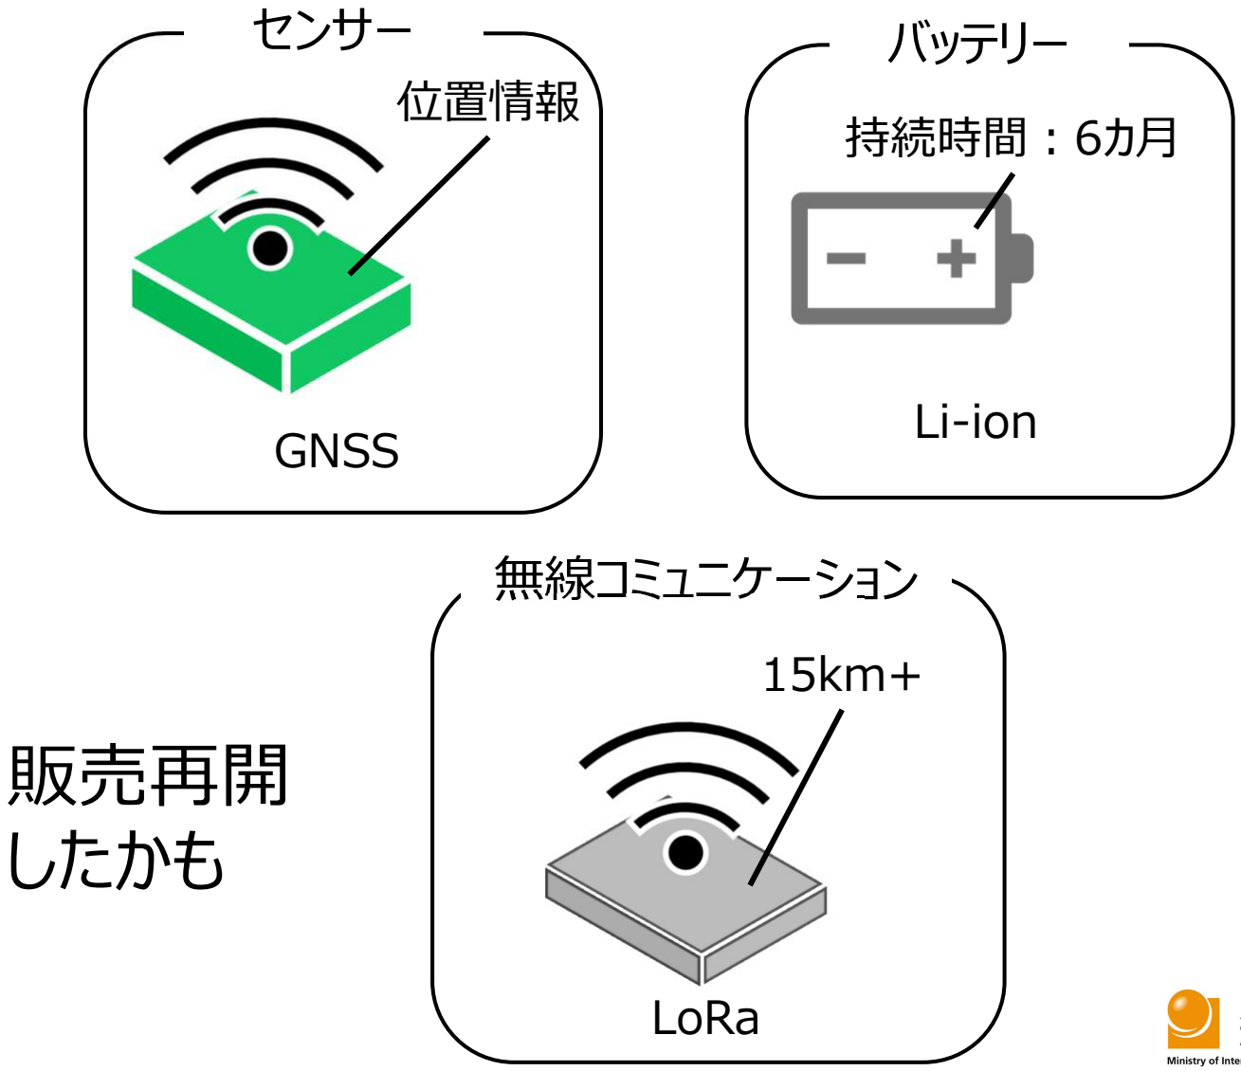
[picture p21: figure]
無線コミュニケーション; LoRa; GNSS; センサー 位置情報; バッテリー; Li-ion; 持続時間:6カ月; 販売再開 したかも

# 1. 主な仕様 すばる1.3

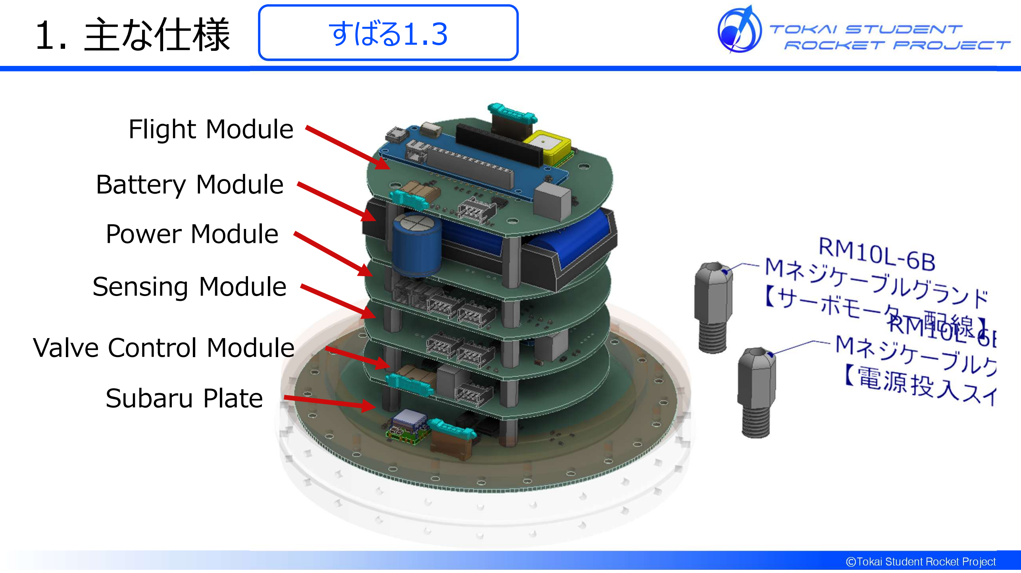
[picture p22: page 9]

©Tokai Student Rocket Project

## Flight Module

## Battery Module Power Module

## Sensing Module

## Valve Control Module Subaru Plate

©Tokai Student Rocket Project

# 1. 主な仕様 水密機能

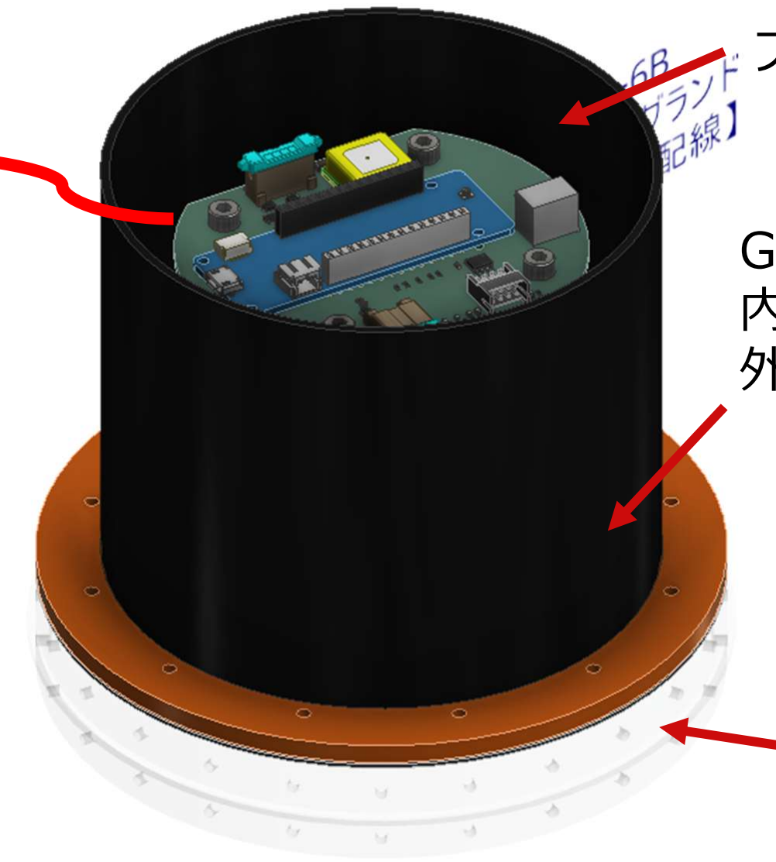
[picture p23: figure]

## GFRPチューブ 内径:118 mm 外形:122 mm 以下

## 計器カプラ（CADはイメージ） カメラ搭載 圧力計測口搭載

## フタが取り付けられる

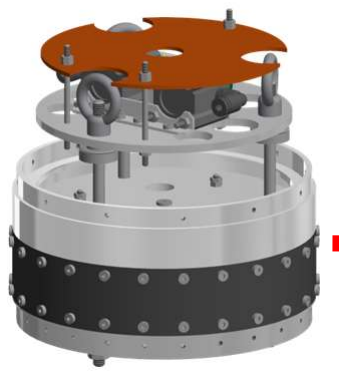
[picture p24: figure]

## 不知火Ⅲ，Ⅳ への配線

©Tokai Student Rocket Project

# 1. 主な仕様 水密機能

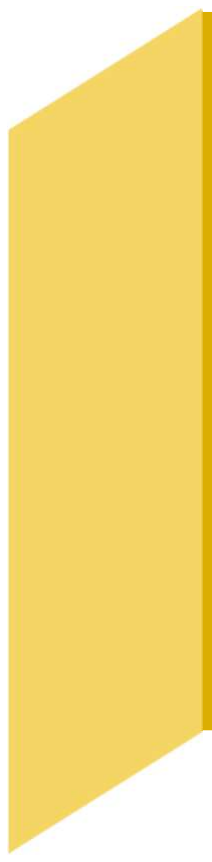
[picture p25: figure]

# PRO

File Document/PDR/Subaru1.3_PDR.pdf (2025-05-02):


©Tokai Student Rocket Project

目次

# 1.主な仕様

# 2.他班との連携

# 3.懸念事項

## PDR

目次

# 1.主な仕様

# 2.他班との連携

# 3.懸念事項

## PDR

## 1. 主な仕様 Flight Module

GNSS; センサー; 位置情報; CAN; コミュニケーション; ネットワーク形成; FeRAM; ログ保存; ロギング; 無線コミュニケーション; ダウンリンク; LoRa; 基板外形; 高変換効率; 電磁弁; 駆動系; 2段分離; Rate:10 Hz; Rate:100 Hz; Rate:2 Hz

スイッチング DCDC コンバータ

# 1. 主な仕様

## Sensing Module

センサー; 角速度; BNO055; 加速度; 地磁気; 無線コミュニケーション; ダウンリンク; LoRa; 基板外形; CAN; コミュニケーション; ネットワーク形成; FeRAM; ログ保存; ロギング; 高変換効率; Rate:100 Hz; Rate:2 Hz

スイッチング DCDC コンバータ

# 1. 主な仕様

## Power Module

基板外形 バッテリー; 電源管理; LTC3118; 電源切替＋コンバータ; センサー; 電力モニタリング; INA219; NTCサーミスター; 最大出力：12V, 2A

# 1. 主な仕様

## Subaru Plate

基板外形; センサー; LPS28DFW; スイッチング DCDC コンバータ; 高変換効率; CAN; コミュニケーション; ネットワーク形成; 駆動系; カメラON; バルブ制御; サーボモータ; Rate:100 Hz

## 1. 主な仕様 LoKo GPS Tracker

Air Unit; Ground Unit; 日本で技適を取得しているか確認
無線コミュニケーション; LoRa; GNSS; センサー; 位置情報; バッテリー; Li-ion; 持続時間：6カ月

技適未取得機器を用いた実験等の特例制度

NO

# 1. 主な仕様 水密機能


概念設計図

成功？

3D プリント ねじ

ガスケット

## フランジ形状＋ガスケット+専用カプラ

# 1. 主な仕様 水密機能 F


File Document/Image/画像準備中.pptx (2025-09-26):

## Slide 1

カメラ 単色塗りつぶし

画像準備中...

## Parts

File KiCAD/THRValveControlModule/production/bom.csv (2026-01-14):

Designator | Footprint | Quantity | Value | LCSC Part #
C1, C2, C6, C7, C8, C9 | 0603 | 6 | 0.1u
C18 | 0603 | 1 | 0.1uF
C4 | CP_Radial_D12.5mm_P5.00mm | 1 | 1000u
D1 | D_SOD-123 | 1 | RB160M-30TR
D2 | D_DO-41_SOD81_P2.54mm_Vertical_KathodeUp | 1 | P4KE15A
D5 | MA_DO-221BC | 1 | MA10EB045
D6 | D_SOD-123 | 1 | 1N4148W
END 120R | SW_CK_JS202011CQN_DPDT_Straight | 1 | IS-2235
J1 | JST_XH_B4B-XH-A_1x04_P2.50mm_Vertical | 1 | B4B-XH-A(LF)(SN)
J2, J3 | JST_XH_B3B-XH-A_1x03_P2.50mm_Vertical | 2 | B3B-XH-A(LF)(SN)
J4 | AMASS_XT30PW-M_1x02_P2.50mm_Horizontal | 1 | XT30PW-M
J5 | DF51A-4P-2DSA | 1 | DF51A-4P-2DSA
J6 | PinHeader_1x04_P2.54mm_Vertical | 1 | SSD1306
J7 | DF51A-8DP-2DS | 1 | DF51A-8DP-2DS
LS1 | UGCT7525AN4 | 1 | UGCT7525AN4
Q1 | SOT-23_Handsoldering | 1 | IRLML6344TRPBFTR
R1, R10, R11, R12, R13, R15, R2, R7, R8 | 0603 | 9 | 10k
R3, R4 | 0603 | 2 | 4.7k
R5, R6 | 0603 | 2 | 120
R9 | 0603 | 1 | 1k
SW A | SKRPACE010 | 1 | SKRPACE010
U1 | XIAO-RA4M1-SMD | 1 | XIAO-RA4M1-SMD
U10 | SOIC-16W_7.5x10.3mm_P1.27mm | 1 | MB85RQ8MX
U2 | StrawberryLinux_ICM-42688-P | 1 | ICM-42688
U3 | StrawberryLinux_ADXL375 | 1 | ADXL375
U4 | SOIC-8_3.9x4.9mm_P1.27mm | 1 | ATA6561
U5 | SOIC-8_3.9x4.9mm_P1.27mm | 1 | MAX485E
U6 | StrawberryLinux_SC8721 | 1 | SC8721
U7 | BP5293-50 | 1 | BP5293-50
U8, U9 | SOT-23-5 | 2 | TC7S14F

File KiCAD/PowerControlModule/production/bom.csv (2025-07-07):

Designator | Footprint | Quantity | Value | LCSC Part #
C1 | CP_Radial_D6.3mm_P2.50mm | 1 | 220uF
C10, C13, C16, C17, C22, C3, C5 | 0603 | 7 | 0.1uF
C11 | CP_Elec_6.3x5.9 | 1 | 33uF
C14, C15 | 0603 | 2 | 15pF
C18, C21 | 0603 | 2 | 0.056uF
C19, C20 | 0603 | 2 | 2.2uF
C2, C4 | 0805 | 2 | 22uF
C9 | CP_Radial_D18.0mm_P7.50mm | 1 | 2200uF
D1, D2 | 0603 | 2 | Orange
D10, D11, D6 | D_SOD-123F | 3 | SS2040FL
D3 | 0603 | 1 | Green
D4, D5 | D_SMA | 2 | SMAJ45A
D7, D8, D9 | 0603 | 3 | Red
H1, H2, H3, H4 | MountingHole_3.2mm_M3_Pad_TopBottom | 4 | MountingHole
J1, J2 | DF1B-2S-2.5R | 2 | DF1B-2S-2.5R
J3 | DF11-8DP-2DS | 1 | DF11-8DP-2DS
PS1 | M78AR03305 | 1 | M78AR05-0.5
Q1, Q2, Q4, Q5, Q7, Q9 | SOT-23_Handsoldering | 6 | AO3401A
Q11, Q12 | SOIC-8_3.9x4.9mm_P1.27mm | 2 | Si4162DY
Q3 | TSOT-23_HandSoldering | 1 | AO3400A
R1, R2, R23, R8 | 0603 | 4 | 4.7kR
R10, R11, R12 | 2512 | 3 | 15mR
R13, R14, R9 | 0603 | 3 | 680R
R15, R16 | 0603 | 2 | 2.7kR
R17 | 0603 | 1 | 820
R18, R4 | 0603 | 2 | 5.6kR
R19 | 0603 | 1 | 5.6kR
R20 | 0603 | 1 | 3.3kR
R21 | 0603 | 1 | 3.6kR
R22, R24, R26, R3, R6, R7 | 0603 | 6 | 10kR
R25 | 0603 | 1 | 120R
R27 | 0603 | 1 | 10k
R5 | 0603 | 1 | 3.3kR
TH1 | PinHeader_1x02_P2.00mm_Vertical | 1 | Thermistor_NTC
U1 | XIAO-RP2040-SMD | 1 | XIAO-RP2040-DIP
U11 | StrawberryLinux_LTC3119 | 1 | LTC3119
U2 | TSSOP-20_4.4x6.5mm_P0.65mm | 1 | MCP2515-xST
U3, U4, U6 | VSSOP-10_3x3mm_P0.5mm | 3 | INA228
U5 | MSOP-16_3x4.039mm_P0.5mm | 1 | LTC4353
U8 | SOIC-8_3.9x4.9mm_P1.27mm | 1 | MCP2562-E-SN
U9 | SOT-23_Handsoldering | 1 | MCP1792x-5002xCB
Y1 | Crystal_HC49-4H_Vertical | 1 | 8MHz

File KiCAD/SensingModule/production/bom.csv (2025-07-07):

Designator | Footprint | Quantity | Value | LCSC Part #
C1 | CP_Elec_10x10 | 1 | 330uF
C10, C11 | 0805 | 2 | 1uF
C14, C15, C16, C4, C5, C6 | 0603 | 6 | 0.1uF
C7, C8 | 0603 | 2 | 15pF
D1, D2, D5, D6 | 0603 | 4 | Blue
D3 | 0603 | 1 | Green
D7 | D_SOD-123F | 1 | SS2040FL
H5, H6, H7, H8 | MountingHole_3.2mm_M3_DIN965_Pad_TopBottom | 4 | MountingHole_Pad
J1 | DF11-8DP-2DS | 1 | DF11-8DP-2DS
J3 | DF51-2P-2DS | 1 | DF51-2P-2DS
J4 | DF51A-4P-2DS | 1 | DF51A-4P-2DS
PS1 | M78AR03305 | 1 | M78AR05-0.5
R1, R12, R13, R2 | 0603 | 4 | 680R
R10 | 0603 | 1 | 2.2kR
R11 | 0603 | 1 | 120R
R14, R15 | 0603 | 2 | 10kR
R17, R5, R6, R7, R8, R9 | 0603 | 6 | 4.7kR
U1 | BOARD_ARDUINO_MKR_WAN_1310 | 1 | ARDUINO_MKR_WAN_1310
U2 | AE-BNO055-BO | 1 | BNO055
U4 | TSSOP-20_4.4x6.5mm_P0.65mm | 1 | MCP2515-xST
U5, U6, U7 | SOIC-16W_7.5x10.3mm_P1.27mm | 3 | MB85RQ8MX
U8 | TSOT-23-5 | 1 | RT9080-33GJ5
U9 | SOIC-8_3.9x4.9mm_P1.27mm | 1 | MCP2562-E-SN
Y1 | Crystal_HC49-4H_Vertical | 1 | 8MHz

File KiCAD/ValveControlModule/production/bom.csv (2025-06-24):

Designator | Footprint | Quantity | Value | LCSC Part #
C1, C11, C12, C13, C14, C18, C3, C4, C5 | 0603 | 9 | 0.1uF
C10, C9 | 0603 | 2 | 1uF
C15 | CP_Elec_10x10 | 1 | 330uF
C16 | CP_Radial_D8.0mm_P3.50mm | 1 | 100uF
C17 | 0805 | 1 | 22uF
C6, C7 | 0603 | 2 | 15pF
D1 | D_SMA | 1 | SMAJ45A
D3 | 0603 | 1 | Green
D9 | D_SMA_Handsoldering | 1 | SB34AFC
H1, H2, H3, H4 | MountingHole_3.2mm_M3_Pad_TopBottom | 4 | MountingHole_Pad
J1, J3 | DF51A-4P-2DS | 2 | DF51A-4P-2DS
J2 | DF11-8DP-2DS | 1 | DF11-8DP-2DS
PS1 | M78AR03305 | 1 | M78AR05-0.5
Q2, Q4 | SOT-23_Handsoldering | 2 | AO3401A
Q3 | SOT-23_Handsoldering | 1 | AO3400A
R1, R6 | 0603 | 2 | 120
R10 | 0603 | 1 | 820R
R11 | 0603 | 1 | 2.4kR
R12, R14, R24, R25, R26, R27 | 0603 | 6 | 10kR
R13 | 0603 | 1 | 100kR
R4 | 0603 | 1 | 10K
R9 | 0603 | 1 | 4.7k
U1 | XIAO-RP2040-SMD | 1 | XIAO-RP2040-DIP
U2 | SOIC-8_3.9x4.9mm_P1.27mm | 1 | LT1785xS8
U3 | SOIC-18W_7.5x11.6mm_P1.27mm | 1 | MCP2515-xSO
U4 | SOIC-8_3.9x4.9mm_P1.27mm | 1 | MCP2562-E-SN
U5 | TSOT-23-5 | 1 | NCV8114BSN330T1G
U6 | SOIC-16W_7.5x10.3mm_P1.27mm | 1 | MB85RQ8MX
U8, U9 | TSOT-23-5_HandSoldering | 2 | TC7S14F
Y1 | Crystal_HC49-4H_Vertical | 1 | 8MHz

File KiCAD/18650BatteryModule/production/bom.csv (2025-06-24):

Designator | Footprint | Quantity | Value | LCSC Part #
BT1, BT2, BT3, BT4 | BAT_1042 | 4 | 1042
D1 | 0603 | 1 | Green
F1 | Fuse_Bourns_MF-RHT300 | 1 | Polyfuse
J1 | DF1B-2S-2.5R | 1 | DF1B-2S-2.5R
J2 | DF11-8DP-2DS | 1 | DF11-8DP-2DS
R1 | 0603 | 1 | 2.4kR
TP1 | TestPoint_THTPad_D1.0mm_Drill0.5mm | 1 | TestPoint
TP2 | TestPoint_THTPad_1.0x1.0mm_Drill0.5mm | 1 | TestPoint_GND

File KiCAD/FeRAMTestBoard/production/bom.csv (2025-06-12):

Designator | Footprint | Quantity | Value | LCSC Part #
C1 | 0603 | 1 | 0.1uF
J1, J2 | PinHeader_1x08_P2.54mm_Vertical | 2 | Conn_01x08
R1 | 0603 | 1 | 4.7kR
U1 | SOIC-16W_7.5x10.3mm_P1.27mm | 1 | MB85RQ8MX

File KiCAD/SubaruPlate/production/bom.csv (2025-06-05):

Designator | Footprint | Quantity | Value | LCSC Part #
C1, C14 | 0603 | 2 | 10uF
C13, C2 | 0603 | 2 | 0.1uF
H1, H2, H3, H4 | MountingHole_3.2mm_M3_Pad_TopBottom | 4 | MountingHole
J1 | PinHeader_1x04_P1.27mm_Vertical | 1 | Wire_Soldering
R1, R14, R16, R2, R3 | 0603 | 5 | 10kR
U1, U6 | CCLGA-7L | 2 | LPS28DFW

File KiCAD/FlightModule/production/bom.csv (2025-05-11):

Designator | Footprint | Quantity | Value | LCSC Part #
BZ1 | Buzzer_12x9.5RM7.6 | 1 | UGCM1205XP
C1 | CP_Elec_10x10 | 1 | 330uF
C10, C11, C16, C17 | 0805 | 4 | 1uF
C13, C14, C15, C18, C4, C5, C8, C9 | 0603 | 8 | 0.1uF
C6, C7 | 0603 | 2 | 15pF
D1, D12, D2, D3, D7 | 0603 | 5 | Blue
D10, D4, D8 | 0603 | 3 | Green
D11, D5, D9 | D_SOD-123F | 3 | GS1010FL
H1, H2, H3, H4 | MountingHole_3.2mm_M3_Pad_TopBottom | 4 | MountingHole_Pad
J1 | DF11-8DP-2DS | 1 | DF11B-8DP-2DS
J4 | DF51-2P-2DS | 1 | DF51-2P-2DS
J5 | DF51A-4P-2DSA | 1 | DF51A-4P-2DSA
PS1 | M78AR03305 | 1 | M78AR05-0.5
Q1, Q2 | SOT-23 | 2 | AO3400A
Q3 | SC-59_Handsoldering | 1 | 2SC3325-Y
R1, R2, R22, R26, R29, R30, R31 | 0603 | 7 | 4.7kR
R11 | 0603 | 1 | 120R
R13, R21, R3, R4, R5 | 0603 | 5 | 680R
R14, R16, R19, R23, R24, R25 | 0603 | 6 | 10kR
R15, R18 | 0603 | 2 | 300R
R17, R20, R6 | 0603 | 3 | 2.4kR
R27 | 0603 | 1 | 100kR
R28 | 0603 | 1 | 0R
U1, U2, U4 | SOIC-16W_7.5x10.3mm_P1.27mm | 3 | MB85RQ8MX
U3 | MODULE_SAM-M8Q-0-10 | 1 | SAM-M8Q-0-10
U5 | TSOT-23-5 | 1 | NCV8114BSN330T1G
U7 | TSOT-23-5_HandSoldering | 1 | TC7S14F
U8 | SOIC-8_3.9x4.9mm_P1.27mm | 1 | MCP2562-E-SN
U9 | TSSOP-20_4.4x6.5mm_P0.65mm | 1 | MCP2515-xST
UX1 | BOARD_ARDUINO_MKR_WAN_1310 | 1 | ARDUINO_MKR_WAN_1310
Y1 | Crystal_SMD_HC49-SD | 1 | 8MHz

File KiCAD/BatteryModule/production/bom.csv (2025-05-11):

Designator | Footprint | Quantity | Value | LCSC Part #
BT1, BT2, BT3, BT4, BT5 | BHC-CR123A | 5 | CR123A
D1 | 0603 | 1 | Green
F1 | Fuse_Bourns_MF-RHT300 | 1 | Polyfuse
J2 | DF1B-2S-2.5R | 1 | DF1B-2S-2.5R
J3 | DF11-8DP-2DS | 1 | DF11-8DP-2DS
R1 | 0603 | 1 | 2.4kR
TP1, TP2 | TestPoint_THTPad_D2.0mm_Drill1.0mm | 2 | TestPoint

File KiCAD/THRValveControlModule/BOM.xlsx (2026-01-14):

No. | 型番 | 単価 | 購入場所 | URL | 備考
1 | ICM-42688 | ¥1320 | ストロベリーリナックス | https://strawberry-linux.com/catalog/items?code=42688
2 | SC8721 | ¥1100 | ストロベリーリナックス | https://strawberry-linux.com/catalog/items?code=18721
3 | XT30PW-M | ¥70 | 秋月電子 | https://akizukidenshi.com/catalog/g/g117949/
4 | MAX485ED | ¥160 | 秋月電子 | https://akizukidenshi.com/catalog/g/g116568
5 | IS-2235 | ¥110 | 秋月電子 | https://akizukidenshi.com/catalog/g/g102627/
6 | SSD1306 | ¥580 | 秋月電子 | https://akizukidenshi.com/catalog/g/g112031/
7 | ADXL375 | ¥2354 | ストロベリーリナックス | https://strawberry-linux.com/catalog/items?code=12112
8 | B4B-XH-A(LF)(SN) | ¥10 | 秋月電子 | https://akizukidenshi.com/catalog/g/g112249/
9 | SK54 | ¥200 | 秋月電子 | https://akizukidenshi.com/catalog/g/g104128/
10 | 35ZLH470MEFC10X16 | ¥40 | 秋月電子 | https://akizukidenshi.com/catalog/g/g102719/
11 | 102010551 | ¥1100 | 秋月電子 | https://akizukidenshi.com/catalog/g/g131171/ | Seeed XIAO RA4M1
12 | MA10EB045 | ¥80 | 秋月電子 | https://akizukidenshi.com/catalog/g/g117496/
13 | RB160M-30TR | ¥150 | 秋月電子 | https://akizukidenshi.com/catalog/g/g101398/
14 | BP5293-50 | ¥240 | 秋月電子 | https://akizukidenshi.com/catalog/g/g111188/
15 | IS-2235 | ¥110 | 秋月電子 | https://akizukidenshi.com/catalog/g/g102627/
16 | TC7S14F | ¥60 | 秋月電子 | https://akizukidenshi.com/catalog/g/g114737/
17
18
19
20
合計 |  | ¥7684

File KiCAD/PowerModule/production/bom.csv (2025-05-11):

Designator | Footprint | Quantity | Value | LCSC Part #
C1, C2, C3, C4, C6, C7 | 0603 | 6 | 0.1uF
C5 | CP_Elec_6.3x5.9 | 1 | 33uF
D1, D2, D3 | 0603 | 3 | Orange
D4 | D_SMB_Handsoldering | 1 | SR54F
J2, J3, J4, J6 | DF1B-2S-2.5R | 4 | DF1B-2S-2.5R
J5, J7 | DF11-8DP-2DS | 2 | DF11-8DP-2DS
J8 | DF51-2P-2DS | 1 | DF51-2P-2DS
Q1, Q2 | SOT-23 | 2 | AO3401A
R1, R14, R15, R3, R4, R6 | 0603 | 6 | 10R
R10, R7, R9 | 0603 | 3 | 2.4kR
R11 | 0603 | 1 | 5.6kR
R12 | 0603 | 1 | 5.6kR
R13 | 0603 | 1 | 3.3kR
R16, R2, R5 | 2816 | 3 | 0.1R
R8 | 0603 | 1 | 100kR
TH1 | PinHeader_1x02_P1.00mm_Vertical | 1 | 10kR
U1, U2, U4 | SOT-23-8 | 3 | INA219BxDCN
U3 | StrawberryLinux_LTC3118 | 1 | ~

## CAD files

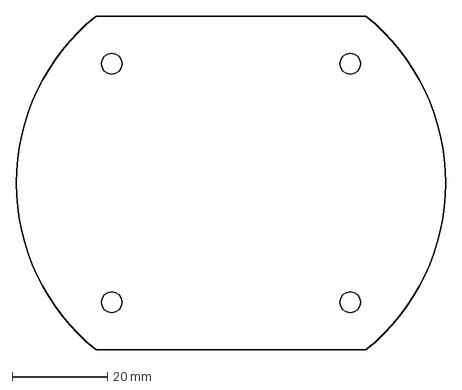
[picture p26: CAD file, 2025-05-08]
Document/DXF/StandardBoard.dxf
90.0 x 70.0 mm

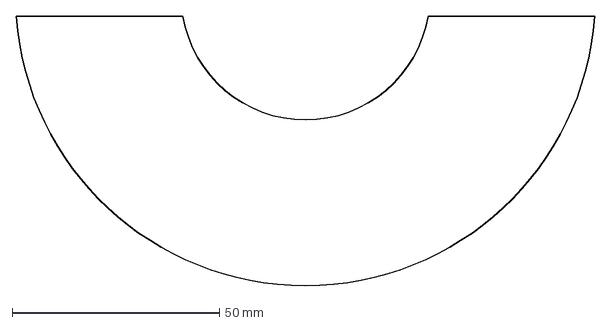
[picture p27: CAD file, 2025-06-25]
KiCAD/Camera_Holder/スケッチ6.dxf
139.6 x 65.0 mm

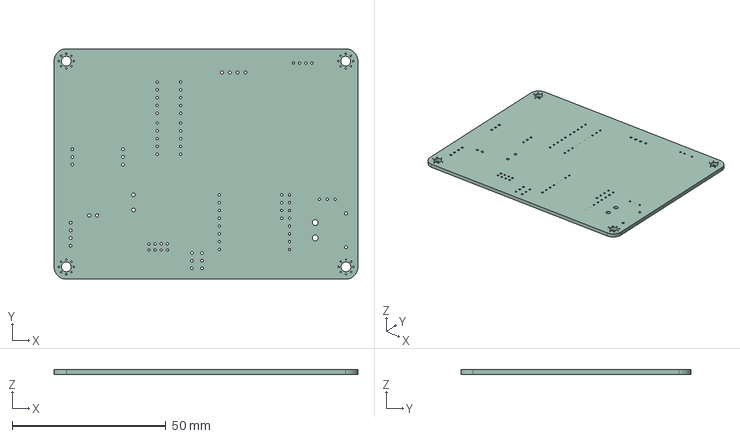
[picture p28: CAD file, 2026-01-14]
KiCAD/THRValveControlModule/THRValveControlModule.step
99.0 x 75.0 x 1.51 mm

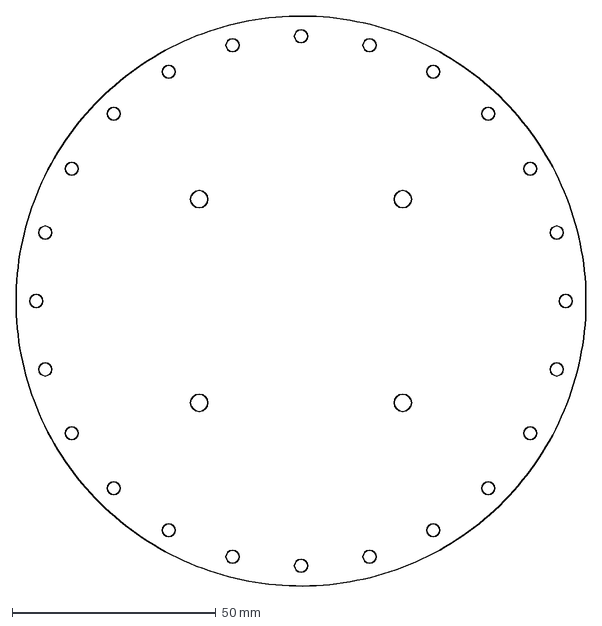
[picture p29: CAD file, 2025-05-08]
Document/DXF/SubaruPlate.dxf
140.0 x 140.0 mm

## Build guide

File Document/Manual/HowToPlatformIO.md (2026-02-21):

# PlatformIO の使い方（簡易ガイド）

## 目次
- [PlatformIO の使い方（簡易ガイド）](#platformio-の使い方簡易ガイド)
  - [目次](#目次)
  - [概要](#概要)
  - [インストール](#インストール)
  - [新規プロジェクトの作成](#新規プロジェクトの作成)
  - [ビルドと書き込み](#ビルドと書き込み)
  - [シリアルモニタ](#シリアルモニタ)
  - [ライブラリ管理](#ライブラリ管理)
  - [トラブルシューティングとコツ](#トラブルシューティングとコツ)
  - [参考（公式）](#参考公式)

---

## 概要
PlatformIO は組み込み開発向けのエコシステムで、複数のボード・フレームワークを統一的に扱えます。コマンドライン（`platformio` / `pio`）または VS Code 拡張で利用できます。

## インストール
- VS Code 拡張: VS Code の拡張から「PlatformIO IDE」をインストール（推奨 GUI）
- CLI（pip）:

```bash
python -m pip install -U pip
python -m pip install -U platformio
```

- インストーラやパッケージマネージャを使う場合は公式サイトを参照してください。

公式サイト: https://platformio.org

公式ドキュメント: https://docs.platformio.org

## 新規プロジェクトの作成
- VS Code: コマンドパレットから "PlatformIO: New Project" を選択して作成

- `platformio.ini` の基本例:

```ini
[env:myboard]
platform = espressif32
board = esp32dev
framework = arduino
```

## ビルドと書き込み

1. VSCodeの左側にあるPlatformIOアイコン (エイリアンの頭のようなアイコン) をクリックする。
2. `Project Tasks` の中から、対象の環境 (`env:***`) を見つける。
3. `Build` をクリックするとコンパイルが実行される。
4. `Upload` をクリックすると、接続されているデバイスにプログラムが書き込まれる。

## シリアルモニタ

1. `Monitor` をクリックすると、シリアルモニターが起動する。

## ライブラリ管理

- `platformio.ini` に `lib_deps` を書くとプロジェクトの依存として自動取得されます。

```ini
lib_deps = 
	adafruit/Adafruit Unified Sensor@^1.0.0
```

## トラブルシューティングとコツ
- ボードIDが不明な場合: `pio boards` で検索
- シリアルポートが競合する場合は他のターミナルを閉じる
- ビルドエラー時は依存と `platformio.ini` の `platform`/`framework` を確認
- キャッシュや古い環境で問題が続く場合は `.pio` フォルダを削除して再ビルド

## 参考（公式）
- PlatformIO 公式サイト: https://platformio.org
- 公式ドキュメント: https://docs.platformio.org

---

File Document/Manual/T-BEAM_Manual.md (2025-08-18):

# T-BEAM 地上局モジュール 取扱説明書

## 1. 概要

このモジュールは、H-62-Avionicsプロジェクトのフライトモジュール用の地上追跡局です。
T-BEAMボードを使用し、フライトモジュールからLoRa無線通信で送信されるテレメトリデータを受信・表示します。また、ボタン操作によりフライトモジュールへコマンドを送信することも可能です。

## 2. ハードウェア

- **T-BEAM:** LoRaモジュール、GPSモジュール、OLEDディスプレイ、ボタンが一体となった開発ボードです。

## 3. 機能

- **テレメトリ受信:** フライトモジュールから送信される各種データをLoRaで受信します。
- **情報表示:** 受信したデータや自身のGPS情報をOLEDディスプレイに表示します。
- **シリアル出力:** 受信した詳細なテレメトリデータをPCのシリアルモニタに出力します。

## 4. 操作方法

### 4.1. 起動

T-BEAMに電源を接続すると、システムが自動的に起動します。ディスプレイに "System Start" と表示された後、待機画面に移行します。

### 4.2. 画面の切り替え

搭載されているボタンを**短く押す**と、ディスプレイの表示ページが切り替わります。ページは2種類あります。

- **ページ0: GPS情報画面**
- **ページ1: バルブ情報画面**

## 5. 表示内容

### 5.1. ページ0: GPS情報画面

```
--- GPS ---      [電波強度]
 H-62 Lat: (緯度)
      Lng: (経度)
=====================
 Now Lat: (現在地の緯度)
     Lng: (現在地の経度)
     Sat: (衛星数)
```

- **電波強度:** LoRaの受信信号強度(RSSI)を5段階のバーで表示します。
- **H-62 Lat/Lng:** フライトモジュールから受信した緯度・経度です。
- **Now Lat/Lng:** このT-BEAMが現在受信しているGPSの緯度・経度です。
- **Sat:** T-BEAMが受信しているGPS衛星の数です。

### 5.2. ページ1: LoRa・バルブ情報画面

```
--- LoRa ---     [電波強度]
  RSSI: (RSSI値) dBm
   SNR: (SNR値) dB
  MAIN: (メインバルブ開度) deg
  SUPPLY: (供給バルブ開度) deg
```

- **電波強度:** LoRaの受信信号強度(RSSI)を5段階のバーで表示します。
- **RSSI:** 受信信号強度(Received Signal Strength Indicator)の具体的な値です。
- **SNR:** 信号対雑音比(Signal-to-Noise Ratio)です。
- **MAIN:** メインバルブの現在の開度(°)です。
- **SUPPLY:** 供給バルブの現在の開度(°)です。

## 6. シリアル出力

USB経由でPCに接続し、シリアルモニタを開くと、フライトモジュールから受信したより詳細なテレメトリデータを確認できます。

**ボーレート:** `115200` (platformio.iniの設定に依存します)

## 7. 運用手順

T-BEAMを運用する際は、以下の点に注意してください。

1. **設置場所:** T-BEAMはGPS信号を受信するため、開けた場所に設置してください。障害物が多い場所では受信精度が低下します。

2. **電源供給:** microUSBケーブルを用いて給電することが可能です。モバイルバッテリー駆動の場合は、残量に注意してください。

3. **LoRa通信:** LoRa通信は長距離通信が可能ですが、環境によっては通信距離が短くなることがあります。定期的に通信状況を確認してください。

4. **データ確認:** シリアルモニタを使用して、受信したテレメトリデータを定期的に確認してください。異常があった場合は、迅速に対応することが重要です。

5. **メンテナンス:** 定期的にハードウェアの点検を行い、異常がないか確認してください。特に、接続端子や配線の状態をチェックすることが重要です。

以下の手順通りに操作を行ってください。
1. **GPS情報画面**を表示します。
- **H-62 Lat/Lng:** フライトモジュールから受信した緯度・経度です。
- **Now Lat/Lng:** このT-BEAMが現在受信しているGPSの緯度・経度です。
- **Sat:** T-BEAMが受信しているGPS衛星の数です。
- **You-> 00 km ->Rocket** 運用者とロケットの
H-62 Lat/Lng の情報を基に，位置情報を船の責任者に伝えます。

2. 船を移動させてもらいます。
3. 機体を回収してください。

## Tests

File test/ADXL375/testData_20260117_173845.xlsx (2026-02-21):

time_ms | acc_x | acc_y | acc_z
0 | -0.96 | 0.48 | 8.65
1 | -1.44 | 0 | 8.65
3 | -0.48 | -0.96 | 9.13
4 | -0.96 | -0.48 | 11.05
5 | -1.92 | 0 | 8.17
6 | 0.96 | 0.48 | 8.17
8 | 0.48 | 0 | 8.17
9 | 3.36 | 1.44 | 8.65
10 | 0.48 | 0 | 7.21
14 | -0.48 | -1.44 | 9.13
15 | -0.96 | 0 | 7.69
16 | -0.96 | 0 | 7.69
20 | 0 | -0.48 | 8.65
20 | 0 | -0.48 | 8.65
21 | -1.44 | -0.48 | 8.17
25 | -0.48 | 0 | 8.65
25 | -0.48 | 0 | 8.65
26 | -0.96 | 0.96 | 9.13
28 | 0.96 | 3.84 | 7.21
32 | 0 | -0.48 | 8.65
33 | -1.92 | 2.4 | 7.21
34 | -0.48 | -0.48 | 7.69
35 | -1.44 | 0.96 | 8.65
36 | -0.48 | 0 | 8.17
38 | -2.4 | 1.92 | 8.65
42 | -0.48 | 0 | 8.65
43 | 0 | 3.36 | 8.17
44 | -0.96 | 0.48 | 8.65
47 | 0 | -0.48 | 7.69
48 | -1.44 | 0 | 6.25
49 | -1.44 | 0 | 6.25
50 | -0.48 | 0 | 9.13
53 | 0 | 0.48 | 9.61
54 | 1.44 | 0 | 10.09
55 | -1.44 | 0.48 | 8.65
60 | -0.96 | 0.48 | 7.69
60 | -0.96 | 0.48 | 7.69
61 | -0.96 | -2.88 | 11.05
63 | 0.96 | -0.96 | 6.73
64 | 0 | 0.96 | 8.65
66 | 0.96 | 0 | 8.17
70 | 0 | 0 | 8.65
70 | 0 | 0 | 8.65
71 | -1.44 | 1.44 | 9.61
75 | -0.96 | 0 | 8.65
75 | -0.96 | 0 | 8.65
76 | 1.44 | 0 | 7.69
78 | -0.48 | -0.96 | 8.65
82 | -0.96 | 0.48 | 8.17
83 | -0.96 | 0.48 | 8.17
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

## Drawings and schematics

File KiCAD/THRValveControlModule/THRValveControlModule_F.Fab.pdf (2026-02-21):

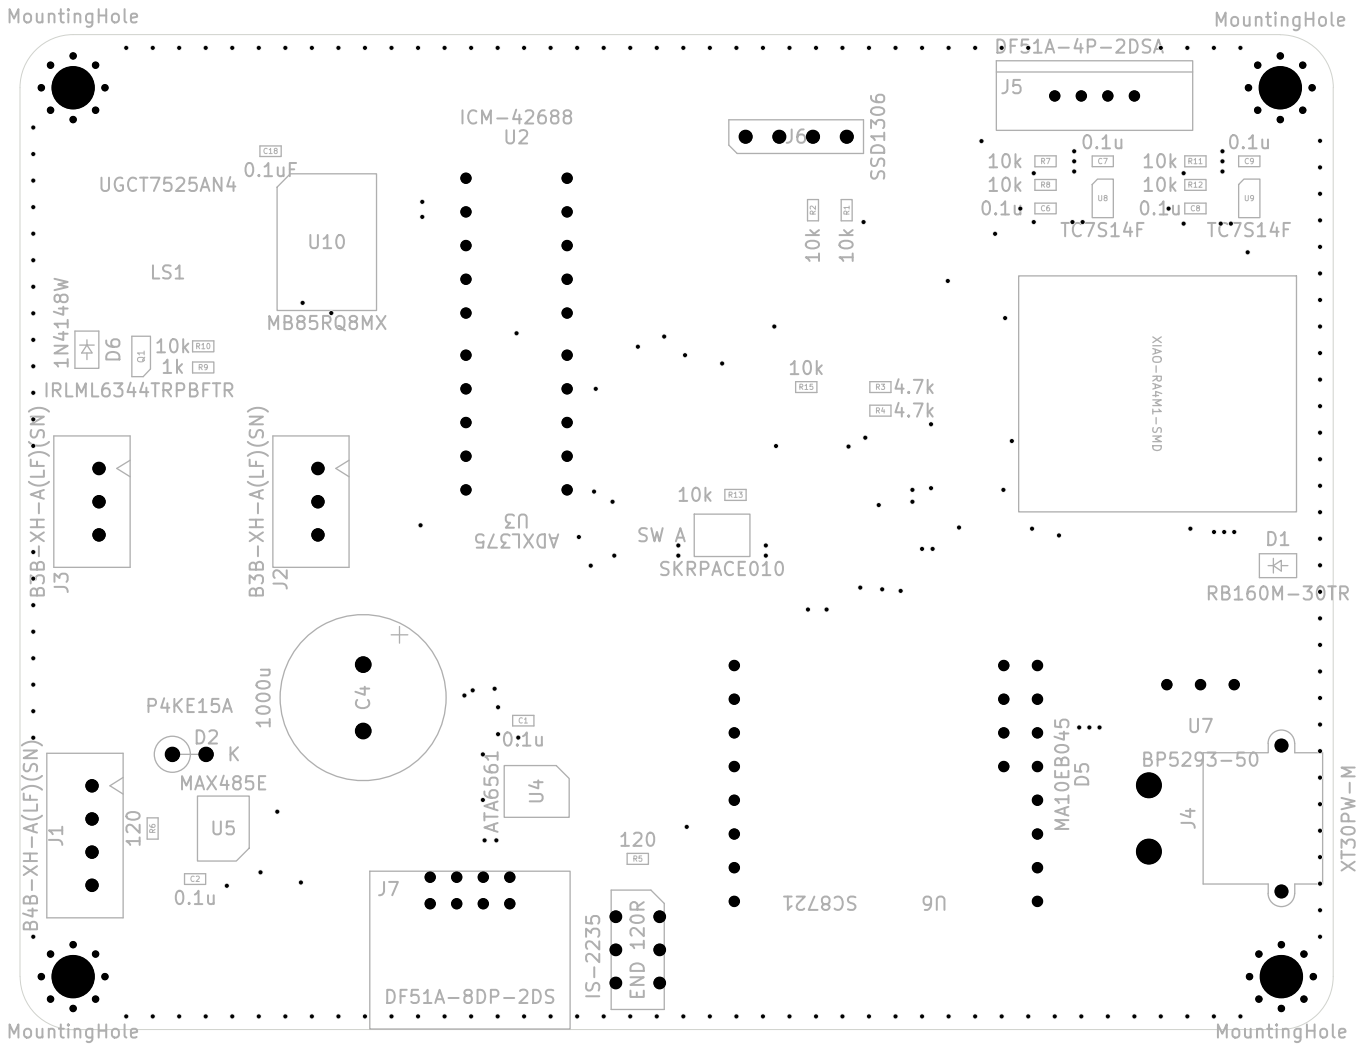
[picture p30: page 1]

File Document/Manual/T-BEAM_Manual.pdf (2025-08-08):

# T-BEAM 地上局モジュール 取扱説明書

1. 概要

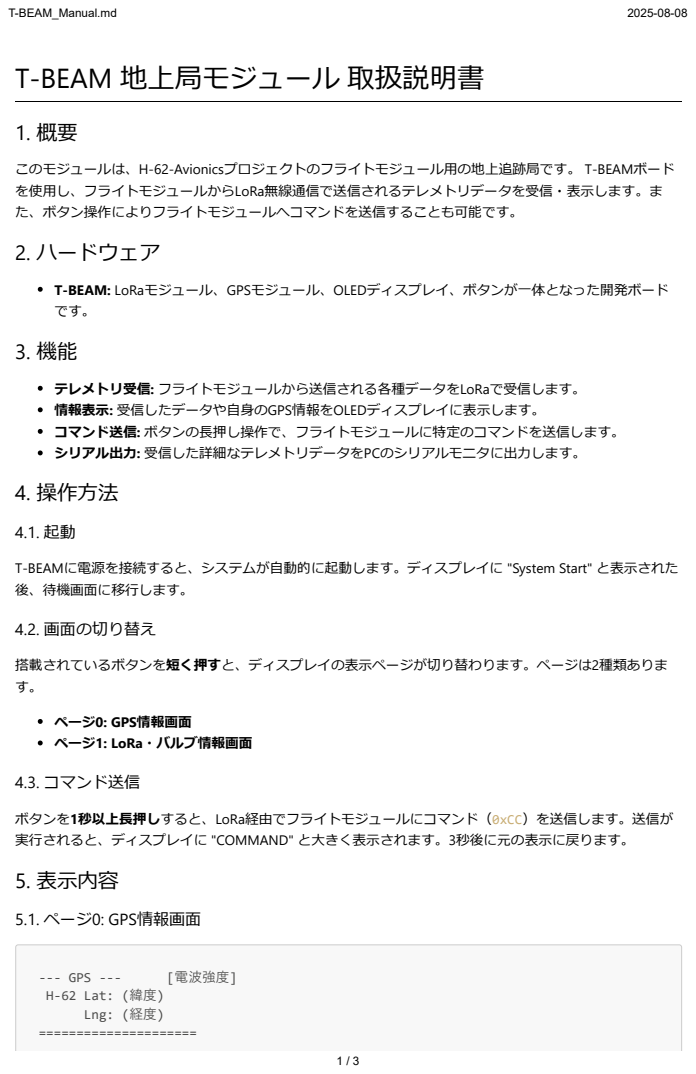
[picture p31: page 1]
T-BEAM_Manual.md; 5.1. ページ0: GPS情報画⾯; --- GPS ---; [電波強度]; H-62 Lat: (緯度) Lng: (経度) =====================

このモジュールは、H-62-Avionicsプロジェクトのフライトモジュール⽤の地上追跡局です。 T-BEAMボード
を使⽤し、フライトモジュールからLoRa無線通信で送信されるテレメトリデータを受信・表⽰します。ま
た、ボタン操作によりフライトモジュールへコマンドを送信することも可能です。
2. ハードウェア

T-BEAM: LoRaモジュール、GPSモジュール、OLEDディスプレイ、ボタンが⼀体となった開発ボード

テレメトリ受信: フライトモジュールから送信される各種データをLoRaで受信します。
情報表⽰: 受信したデータや⾃⾝のGPS情報をOLEDディスプレイに表⽰します。
コマンド送信: ボタンの⻑押し操作で、フライトモジュールに特定のコマンドを送信します。
シリアル出⼒: 受信した詳細なテレメトリデータをPCのシリアルモニタに出⼒します。

T-BEAMに電源を接続すると、システムが⾃動的に起動します。ディスプレイに "System Start" と表⽰された
後、待機画⾯に移⾏します。
4.2. 画⾯の切り替え
搭載されているボタンを短く押すと、ディスプレイの表⽰ページが切り替わります。ページは2種類ありま
ページ0: GPS情報画⾯
ページ1: LoRa・バルブ情報画⾯
4.3. コマンド送信

ボタンを1秒以上⻑押しすると、LoRa経由でフライトモジュールにコマンド（0xCC）を送信します。送信が
実⾏されると、ディスプレイに "COMMAND" と⼤きく表⽰されます。3秒後に元の表⽰に戻ります。

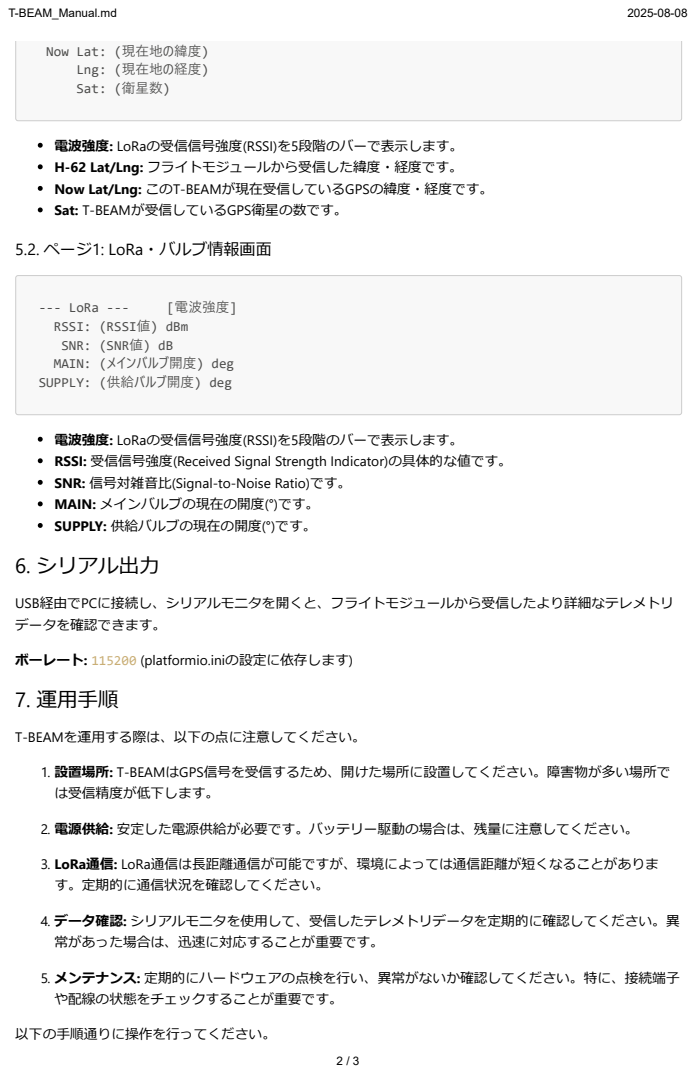
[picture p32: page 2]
--- LoRa ---; [電波強度]

Now Lat: (現在地の緯度)
Lng: (現在地の経度)
Sat: (衛星数)

電波強度: LoRaの受信信号強度(RSSI)を5段階のバーで表⽰します。
H-62 Lat/Lng: フライトモジュールから受信した緯度・経度です。
Now Lat/Lng: このT-BEAMが現在受信しているGPSの緯度・経度です。
Sat: T-BEAMが受信しているGPS衛星の数です。
5.2. ページ1: LoRa・バルブ情報画⾯

RSSI: (RSSI値) dBm
SNR: (SNR値) dB
MAIN: (メインバルブ開度) deg
SUPPLY: (供給バルブ開度) deg

RSSI: 受信信号強度(Received Signal Strength Indicator)の具体的な値です。
SNR: 信号対雑⾳⽐(Signal-to-Noise Ratio)です。
MAIN: メインバルブの現在の開度(°)です。
SUPPLY: 供給バルブの現在の開度(°)です。
6. シリアル出⼒

USB経由でPCに接続し、シリアルモニタを開くと、フライトモジュールから受信したより詳細なテレメトリ
データを確認できます。

ボーレート: 115200 (platformio.iniの設定に依存します)

T-BEAMを運⽤する際は、以下の点に注意してください。
1. 設置場所: T-BEAMはGPS信号を受信するため、開けた場所に設置してください。障害物が多い場所で
は受信精度が低下します。
2. 電源供給: 安定した電源供給が必要です。バッテリー駆動の場合は、残量に注意してください。
3. LoRa通信: LoRa通信は⻑距離通信が可能ですが、環境によっては通信距離が短くなることがありま
す。定期的に通信状況を確認してください。
4. データ確認: シリアルモニタを使⽤して、受信したテレメトリデータを定期的に確認してください。異
常があった場合は、迅速に対応することが重要です。
5. メンテナンス: 定期的にハードウェアの点検を⾏い、異常がないか確認してください。特に、接続端⼦
や配線の状態をチェックすることが重要です。
以下の⼿順通りに操作を⾏ってください。

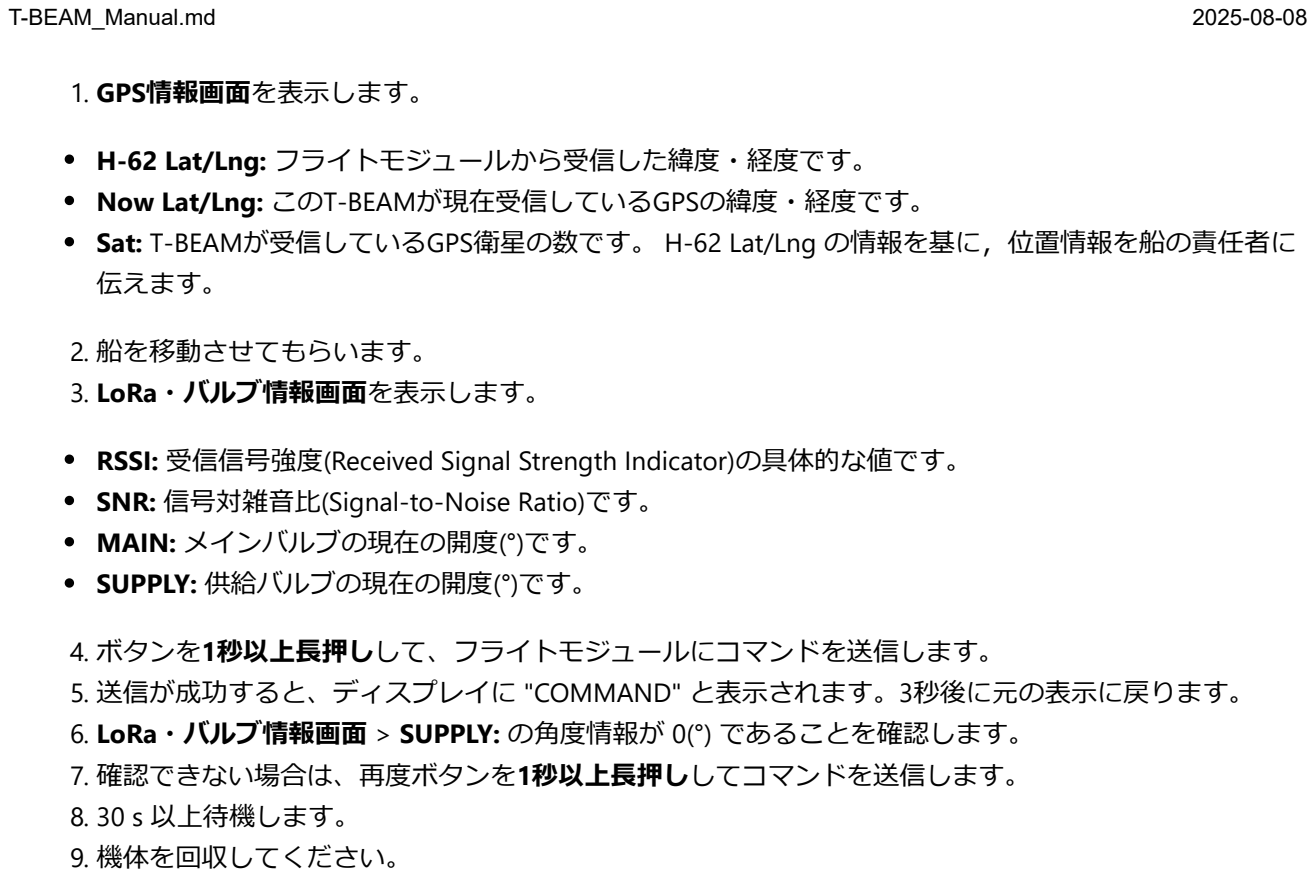
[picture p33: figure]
1. GPS情報画⾯を表⽰します。; H-62 Lat/Lng: フライトモジュールから受信した緯度・経度です。 Now Lat/Lng: このT-BEAMが現在受信しているGPSの緯度・経度です。 Sat: T-BEAMが受信しているGPS衛星の数です。 H-62 Lat/Lng の情報を基に，位置情報を船の責任者に 伝えます。; 2. 船を移動させてもらいます。 3. LoRa・バルブ情報画⾯を表⽰します。; RSSI: 受信信号強度(Received Signal Strength Indicator)の具体的な値です。 SNR: 信号対雑⾳⽐(Signal-to-Noise Ratio)です。 MAIN: メインバルブの現在の開度(°)です。 SUPPLY: 供給バルブの現在の開度(°)です。; 4. ボタンを1秒以上⻑押しして、フライトモジュールにコマンドを送信します。; 7. 確認できない場合は、再度ボタンを1秒以上⻑押ししてコマンドを送信します。 8. 30 s 以上待機します。 9. 機体を回収してください。

5. 送信が成功すると、ディスプレイに "COMMAND" と表⽰されます。3秒後に元の表⽰に戻ります。
6. LoRa・バルブ情報画⾯ > SUPPLY: の⾓度情報が 0(°) であることを確認します。

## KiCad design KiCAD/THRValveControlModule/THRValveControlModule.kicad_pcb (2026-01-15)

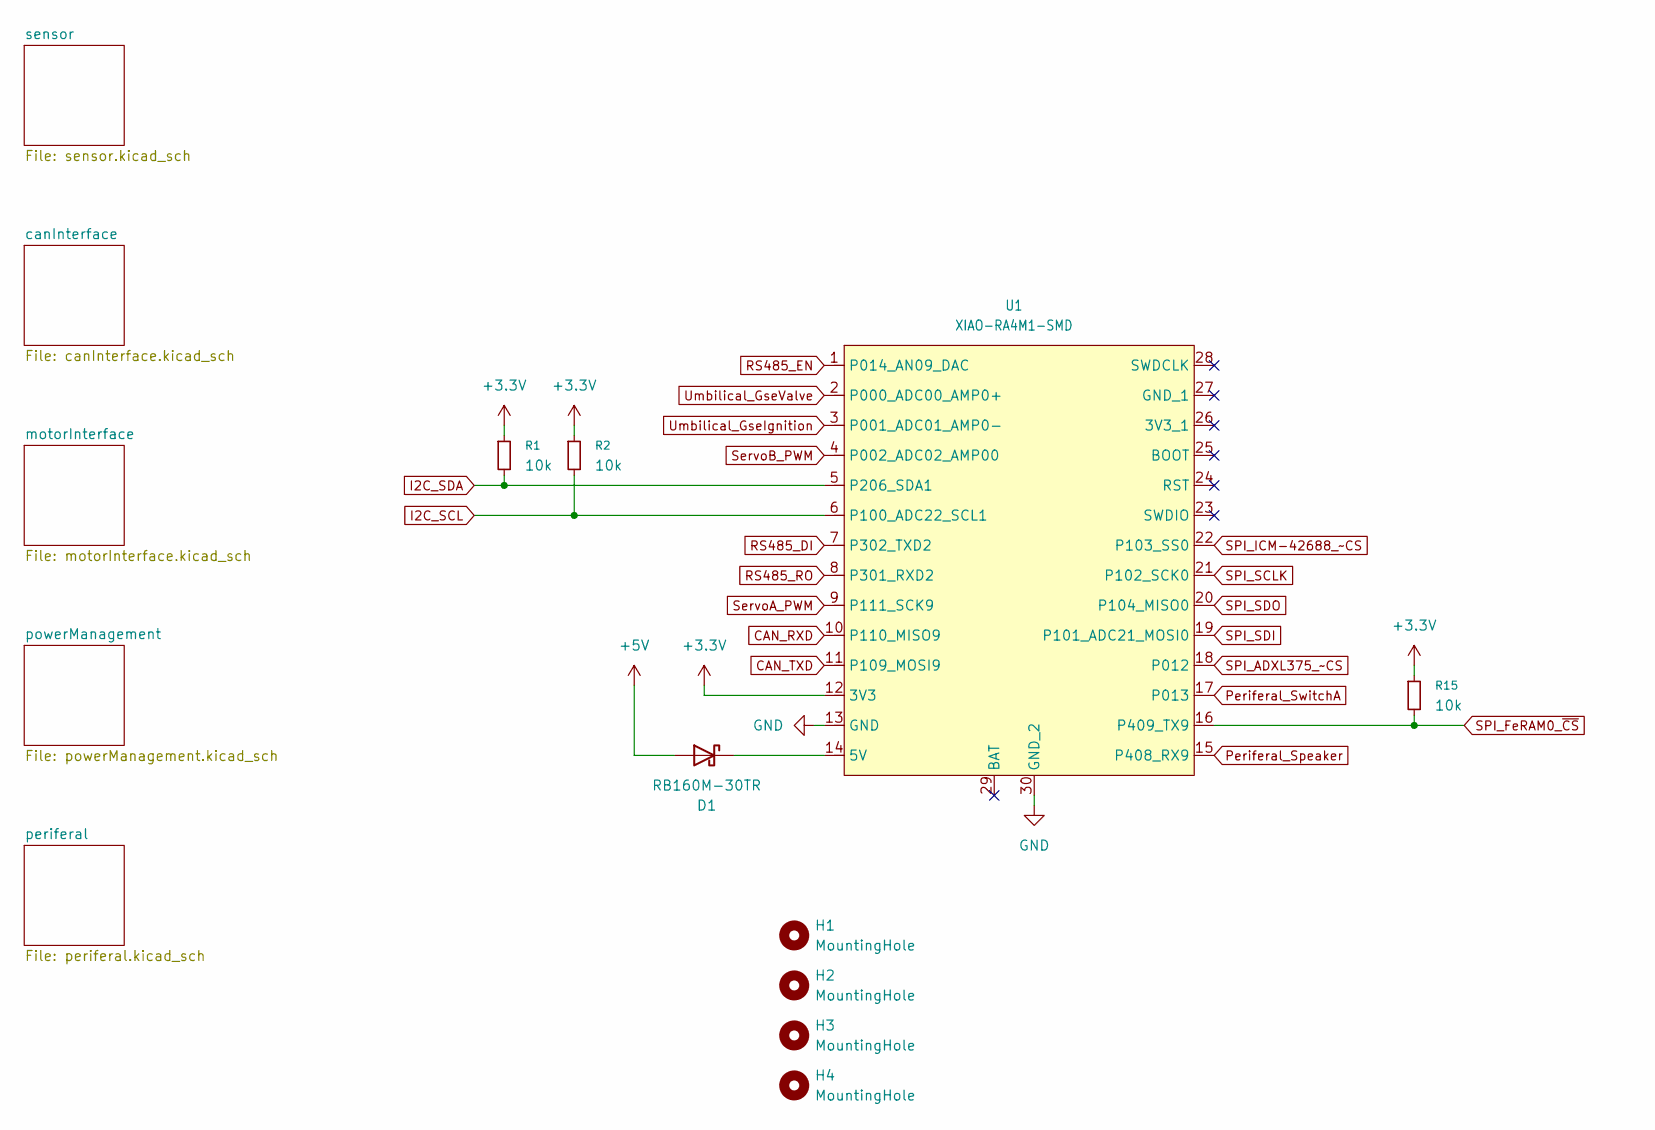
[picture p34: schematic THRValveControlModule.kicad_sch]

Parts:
D1: RB160M-30TR; D_SOD-123
H1, H2, H3, H4: MountingHole; MountingHole_3.2mm_M3_Pad_Via
R1, R2, R15: 10k; R_0603_1608Metric_Pad0.98x0.95mm_HandSolder
U1: XIAO-RA4M1-SMD

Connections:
+3.3V: R1.1, R2.1, R15.1, U1.12 (3V3); also elsewhere on the board
+5V: D1.2 (A); also elsewhere on the board
CAN_RXD: U1.10 (P110_MISO9); also elsewhere on the board
CAN_TXD: U1.11 (P109_MOSI9); also elsewhere on the board
GND: U1.13 (GND), U1.30 (GND_2); also elsewhere on the board
I2C_SCL: R2.2, U1.6 (P100_ADC22_SCL1); also elsewhere on the board
I2C_SDA: R1.2, U1.5 (P206_SDA1); also elsewhere on the board
unnamed: D1.1 (K), U1.14 (5V)
Periferal_Speaker: U1.15 (P408_RX9); also elsewhere on the board
Periferal_SwitchA: U1.17 (P013); also elsewhere on the board
RS485_DI: U1.7 (P302_TXD2); also elsewhere on the board
RS485_EN: U1.1 (P014_AN09_DAC); also elsewhere on the board
RS485_RO: U1.8 (P301_RXD2); also elsewhere on the board
SPI_ADXL375_~CS: U1.18 (P012); also elsewhere on the board
SPI_FeRAM0_~CS: R15.2, U1.16 (P409_TX9); also elsewhere on the board
SPI_ICM-42688_~CS: U1.22 (P103_SS0); also elsewhere on the board
SPI_SCLK: U1.21 (P102_SCK0); also elsewhere on the board
SPI_SDI: U1.19 (P101_ADC21_MOSI0); also elsewhere on the board
SPI_SDO: U1.20 (P104_MISO0); also elsewhere on the board
ServoA_PWM: U1.9 (P111_SCK9); also elsewhere on the board
ServoB_PWM: U1.4 (P002_ADC02_AMP00); also elsewhere on the board
Umbilical_GseIgnition: U1.3 (P001_ADC01_AMP0-); also elsewhere on the board
Umbilical_GseValve: U1.2 (P000_ADC00_AMP0+); also elsewhere on the board

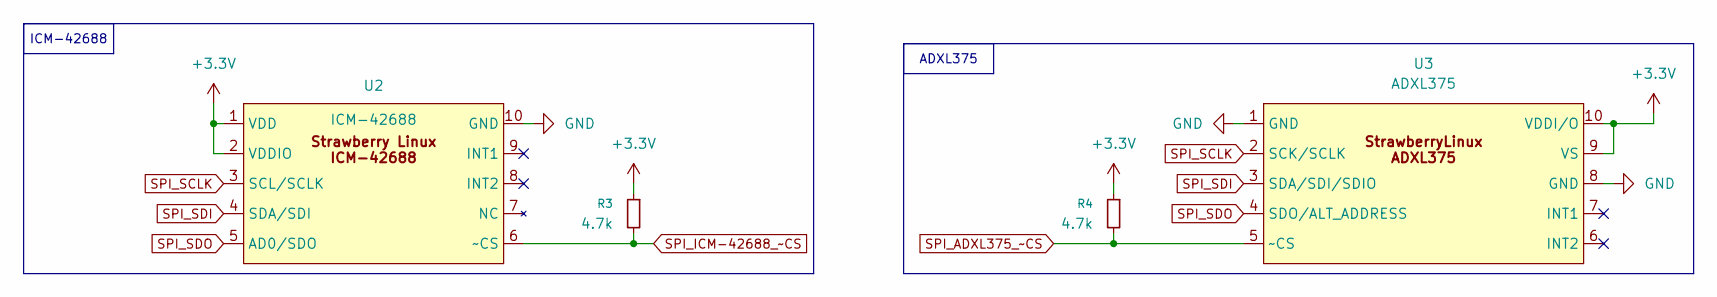
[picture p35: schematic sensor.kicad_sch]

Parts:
R3, R4: 4.7k; R_0603_1608Metric_Pad0.98x0.95mm_HandSolder
U2: ICM-42688; StrawberryLinux_ICM-42688-P
U3: ADXL375; StrawberryLinux_ADXL375

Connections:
+3.3V: R3.1, R4.1, U2.1 (VDD), U2.2 (VDDIO), U3.9 (VS), U3.10 (VDDI/O); also elsewhere on the board
GND: U2.10 (GND), U3.1 (GND), U3.8 (GND); also elsewhere on the board
SPI_ADXL375_~CS: R4.2, U3.5 (~CS); also elsewhere on the board
SPI_ICM-42688_~CS: R3.2, U2.6 (~CS); also elsewhere on the board
SPI_SCLK: U2.3 (SCL/SCLK), U3.2 (SCK/SCLK); also elsewhere on the board
SPI_SDI: U2.4 (SDA/SDI), U3.3 (SDA/SDI/SDIO); also elsewhere on the board
SPI_SDO: U2.5 (AD0/SDO), U3.4 (SDO/ALT_ADDRESS); also elsewhere on the board

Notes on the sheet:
ICM-42688
ADXL375

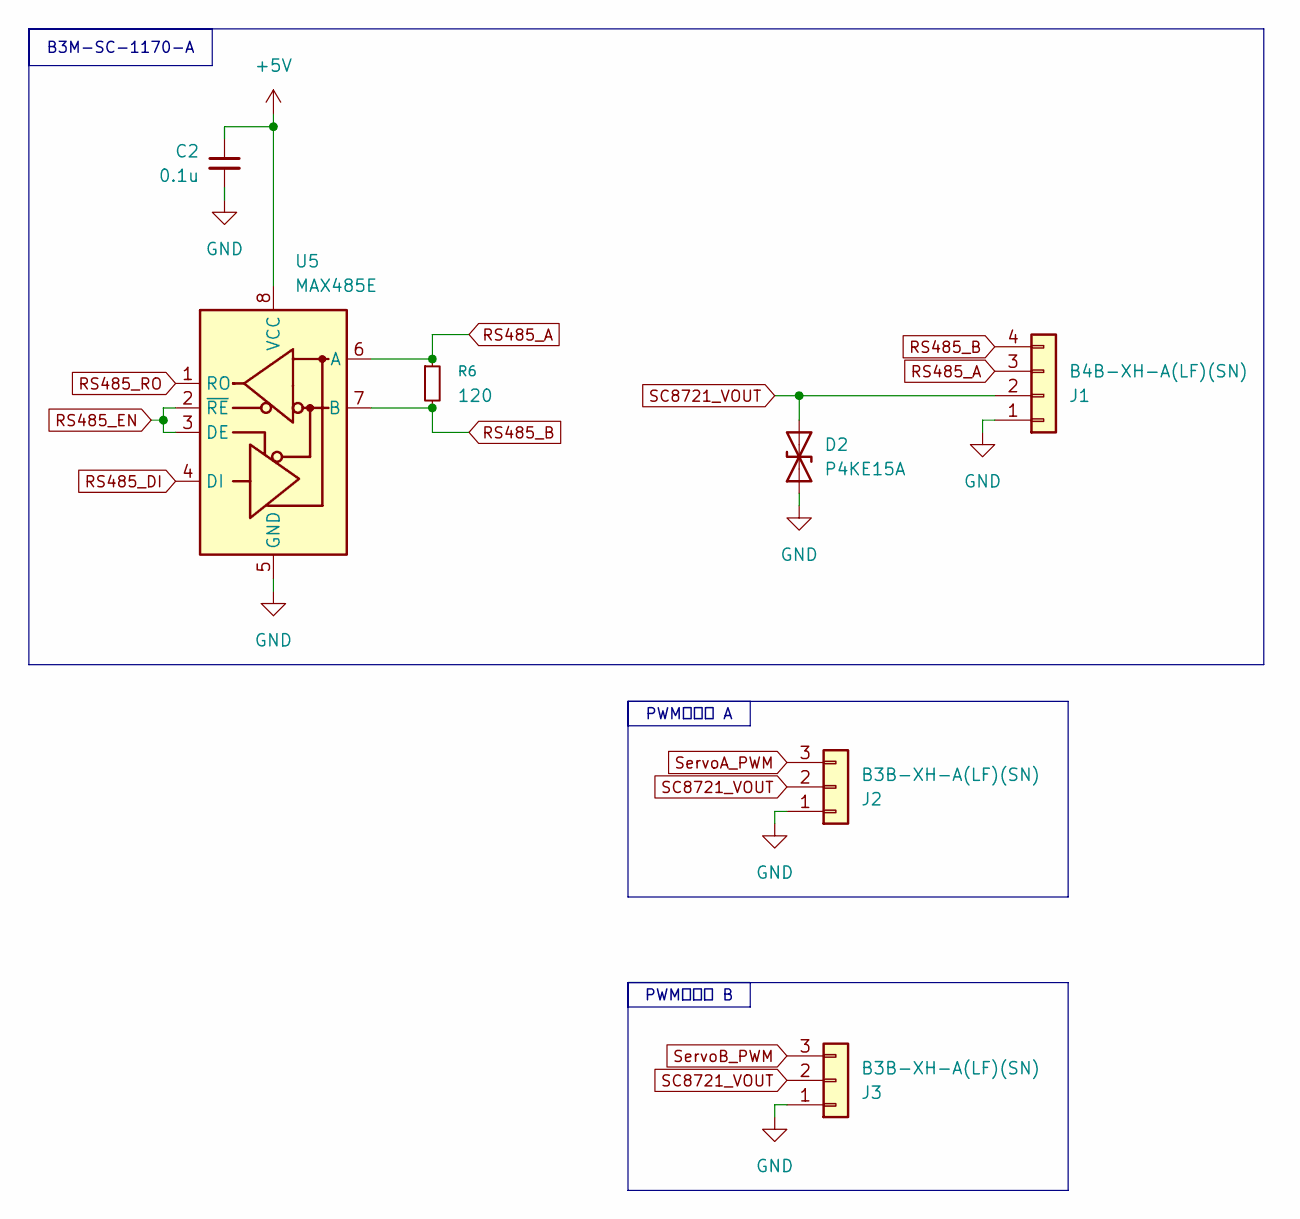
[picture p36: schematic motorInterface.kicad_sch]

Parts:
C2: 0.1u; C_0603_1608Metric_Pad1.08x0.95mm_HandSolder
D2: P4KE15A; D_DO-41_SOD81_P2.54mm_Vertical_KathodeUp
J1: B4B-XH-A(LF)(SN); JST_XH_B4B-XH-A_1x04_P2.50mm_Vertical
J2, J3: B3B-XH-A(LF)(SN); JST_XH_B3B-XH-A_1x03_P2.50mm_Vertical
R6: 120; R_0603_1608Metric_Pad0.98x0.95mm_HandSolder
U5: MAX485E; SOIC-8_3.9x4.9mm_P1.27mm

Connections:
+5V: C2.1, U5.8 (VCC); also elsewhere on the board
GND: C2.2, D2.1 (A1), J1.1, J2.1, J3.1, U5.5 (GND); also elsewhere on the board
RS485_A: J1.3, R6.1, U5.6 (A)
RS485_B: J1.4, R6.2, U5.7 (B)
RS485_DI: U5.4 (DI); also elsewhere on the board
RS485_EN: U5.2 (~RE), U5.3 (DE); also elsewhere on the board
RS485_RO: U5.1 (RO); also elsewhere on the board
SC8721_VOUT: D2.2 (A2), J1.2, J2.2, J3.2; also elsewhere on the board
ServoA_PWM: J2.3; also elsewhere on the board
ServoB_PWM: J3.3; also elsewhere on the board

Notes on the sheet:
PWMサーボ A
PWMサーボ B
B3M-SC-1170-A

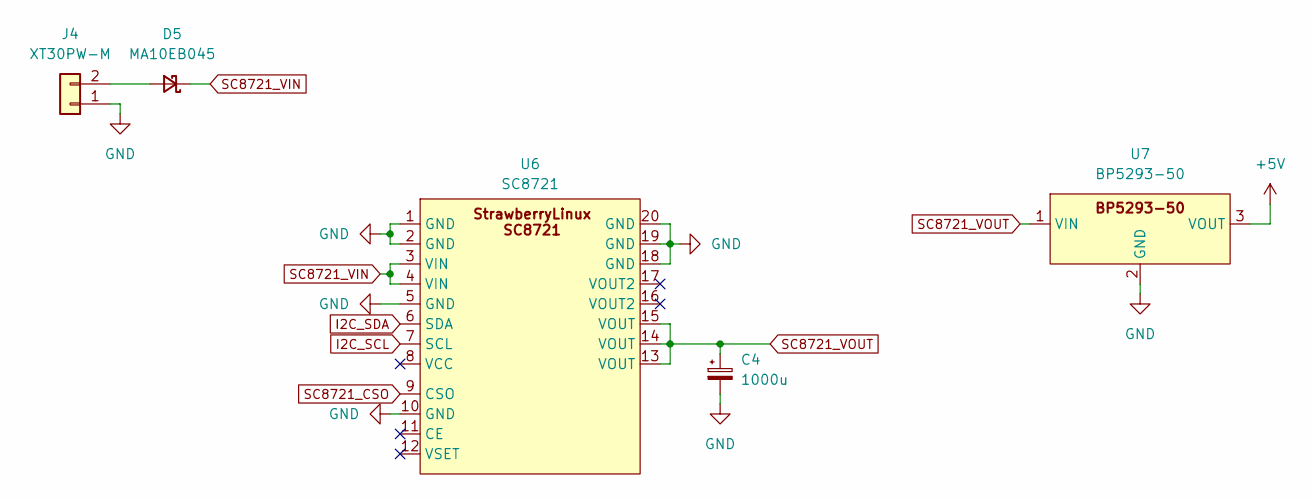
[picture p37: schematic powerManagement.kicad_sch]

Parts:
C4: 1000u; CP_Radial_D12.5mm_P5.00mm
D5: MA10EB045; MA_DO-221BC
J4: XT30PW-M; AMASS_XT30PW-M_1x02_P2.50mm_Horizontal
U6: SC8721; StrawberryLinux_SC8721
U7: BP5293-50

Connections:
+5V: U7.3 (VOUT); also elsewhere on the board
GND: C4.2, J4.1, U6.1 (GND), U6.2 (GND), U6.5 (GND), U6.10 (GND), U6.18 (GND), U6.19 (GND), U6.20 (GND), U7.2 (GND); also elsewhere on the board
I2C_SCL: U6.7 (SCL); also elsewhere on the board
I2C_SDA: U6.6 (SDA); also elsewhere on the board
unnamed: D5.2 (A), J4.2
SC8721_CSO: U6.9 (CSO)
SC8721_VIN: D5.1 (K), U6.3 (VIN), U6.4 (VIN)
SC8721_VOUT: C4.1, U6.13 (VOUT), U6.14 (VOUT), U6.15 (VOUT), U7.1 (VIN); also elsewhere on the board

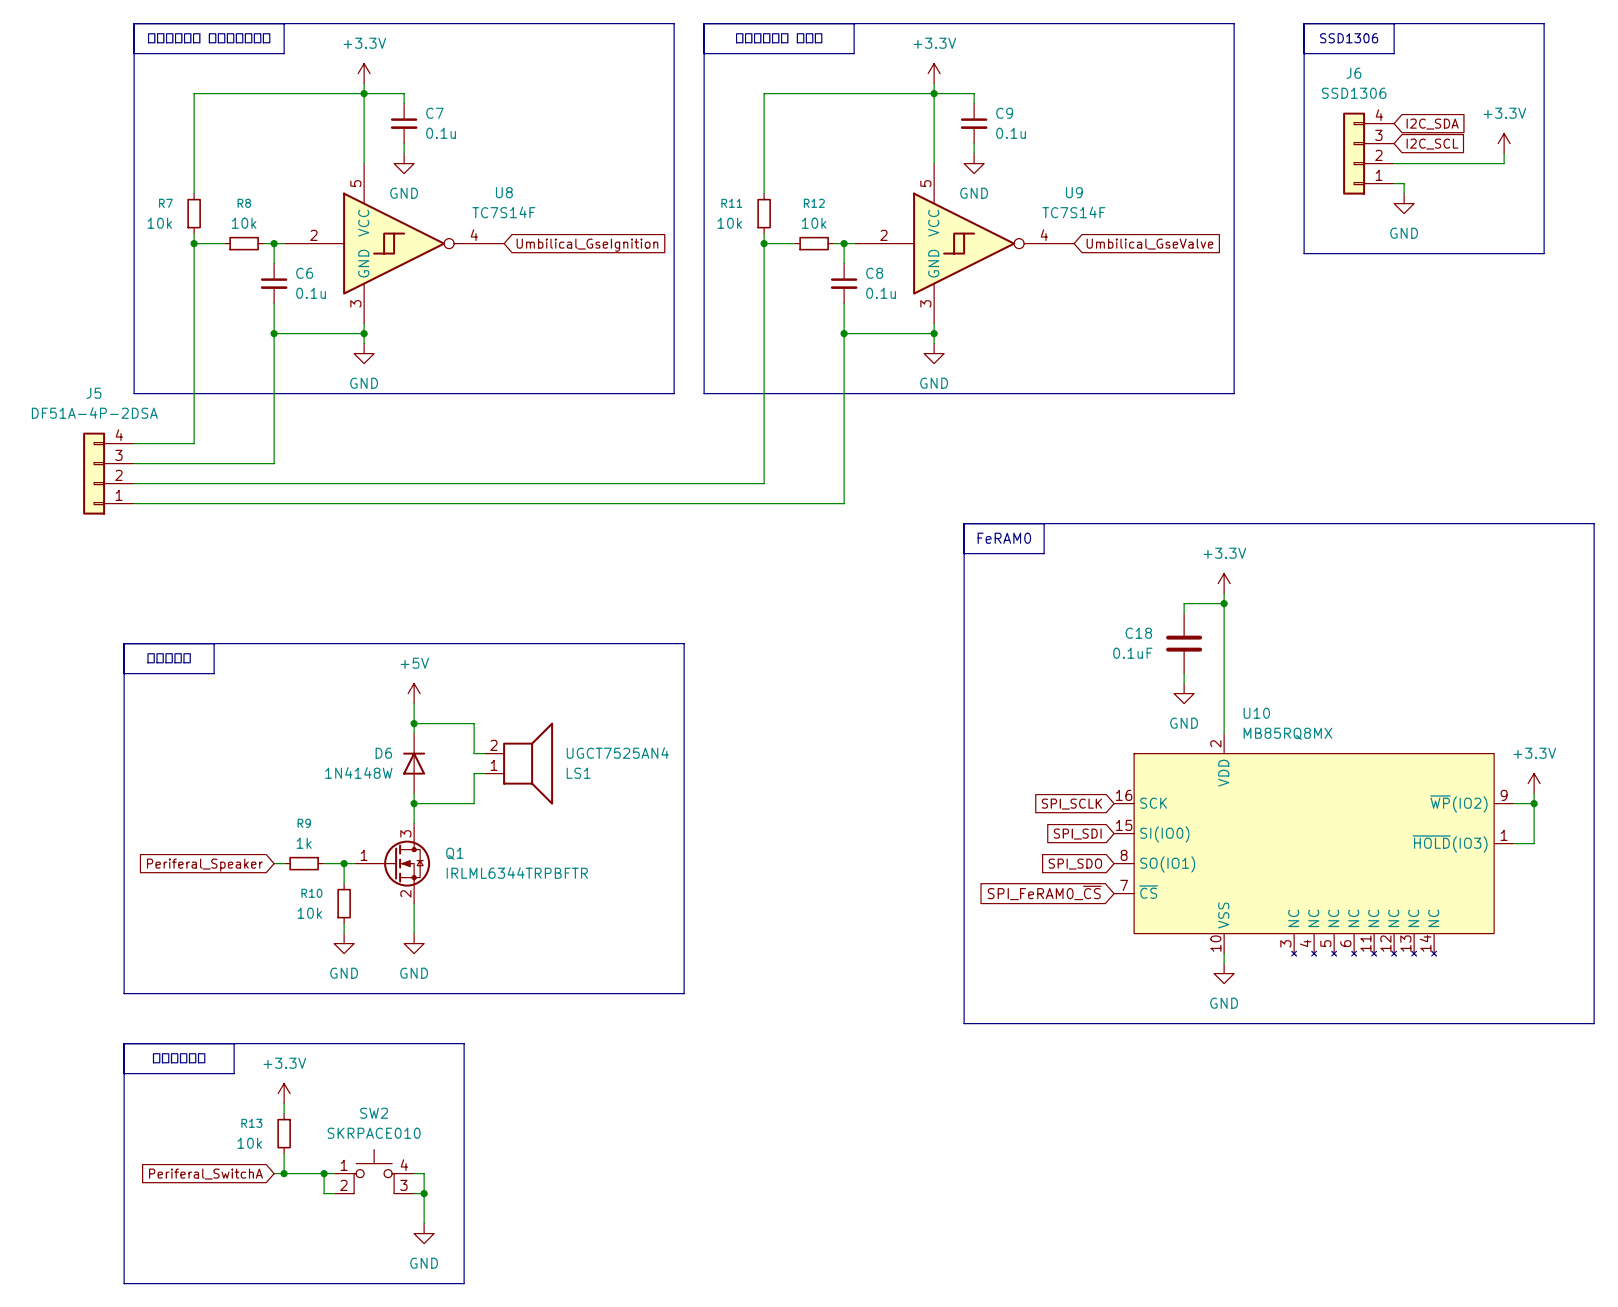
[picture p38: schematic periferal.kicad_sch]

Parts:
C6, C7, C8, C9: 0.1u; C_0603_1608Metric_Pad1.08x0.95mm_HandSolder
C18: 0.1uF; C_0603_1608Metric_Pad1.08x0.95mm_HandSolder
D6: 1N4148W; D_SOD-123
J5: DF51A-4P-2DSA
J6: SSD1306; PinHeader_1x04_P2.54mm_Vertical
LS1: UGCT7525AN4
Q1: IRLML6344TRPBFTR; SOT-23_Handsoldering
R7, R8, R10, R11, R12, R13: 10k; R_0603_1608Metric_Pad0.98x0.95mm_HandSolder
R9: 1k; R_0603_1608Metric_Pad0.98x0.95mm_HandSolder
SW2: SKRPACE010
U8, U9: TC7S14F; SOT-23-5
U10: MB85RQ8MX; SOIC-16W_7.5x10.3mm_P1.27mm

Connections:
+3.3V: C7.1, C9.1, C18.1, J6.2, R7.2, R11.2, R13.1, U8.5 (VCC), U9.5 (VCC), U10.1 (~HOLD(IO3)), U10.2 (VDD), U10.9 (~WP(IO2)); also elsewhere on the board
+5V: D6.1 (K), LS1.2; also elsewhere on the board
GND: C6.2, C7.2, C8.2, C9.2, C18.2, J5.1, J5.3, J6.1, Q1.2 (S), R10.1, SW2.3 (K), SW2.4 (A), U8.3 (GND), U9.3 (GND), U10.10 (VSS); also elsewhere on the board
I2C_SCL: J6.3; also elsewhere on the board
I2C_SDA: J6.4; also elsewhere on the board
unnamed: C6.1, R8.2, U8.2
unnamed: C8.1, R12.2, U9.2
unnamed: D6.2 (A), LS1.1, Q1.3 (D)
unnamed: J5.2, R11.1, R12.1
unnamed: J5.4, R7.1, R8.1
unnamed: Q1.1 (G), R9.1, R10.2
Periferal_Speaker: R9.2; also elsewhere on the board
Periferal_SwitchA: R13.2, SW2.1, SW2.2; also elsewhere on the board
SPI_FeRAM0_~CS: U10.7 (~CS); also elsewhere on the board
SPI_SCLK: U10.16 (SCK); also elsewhere on the board
SPI_SDI: U10.15 (SI(IO0)); also elsewhere on the board
SPI_SDO: U10.8 (SO(IO1)); also elsewhere on the board
Umbilical_GseIgnition: U8.4; also elsewhere on the board
Umbilical_GseValve: U9.4; also elsewhere on the board

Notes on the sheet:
アンビリカル イグニッション
SSD1306
アンビリカル バルブ
FeRAM0
ユーザー入力
スピーカー

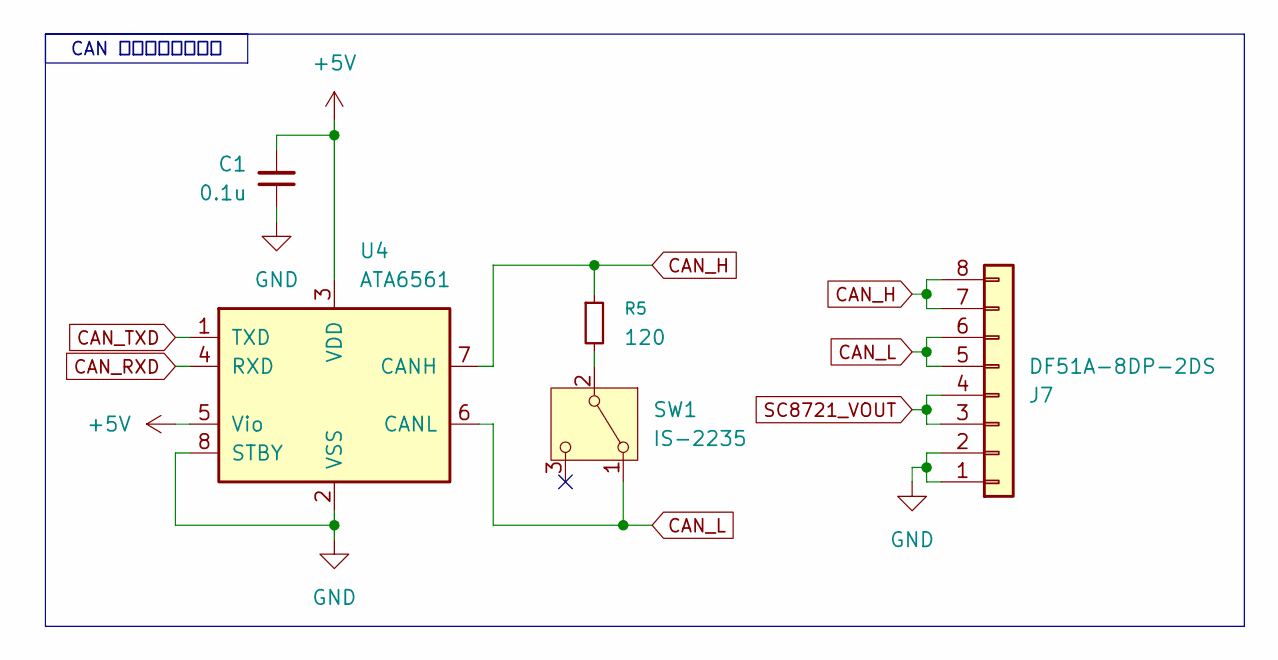
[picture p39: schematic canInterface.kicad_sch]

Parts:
C1: 0.1u; C_0603_1608Metric_Pad1.08x0.95mm_HandSolder
J7: DF51A-8DP-2DS
R5: 120; R_0603_1608Metric_Pad0.98x0.95mm_HandSolder
SW1: IS-2235; SW_CK_JS202011CQN_DPDT_Straight
U4: ATA6561; SOIC-8_3.9x4.9mm_P1.27mm

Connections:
+5V: C1.2, U4.3 (VDD), U4.5 (Vio); also elsewhere on the board
CAN_H: J7.7, J7.8, R5.1, U4.7 (CANH)
CAN_L: J7.5, J7.6, SW1.1 (A), U4.6 (CANL); also elsewhere on the board
CAN_RXD: U4.4 (RXD); also elsewhere on the board
CAN_TXD: U4.1 (TXD); also elsewhere on the board
GND: C1.1, J7.1, J7.2, U4.2 (VSS), U4.8 (STBY); also elsewhere on the board
unnamed 17: R5.2, SW1.2 (B); also elsewhere on the board
SC8721_VOUT: J7.3, J7.4; also elsewhere on the board

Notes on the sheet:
CAN インターフェース

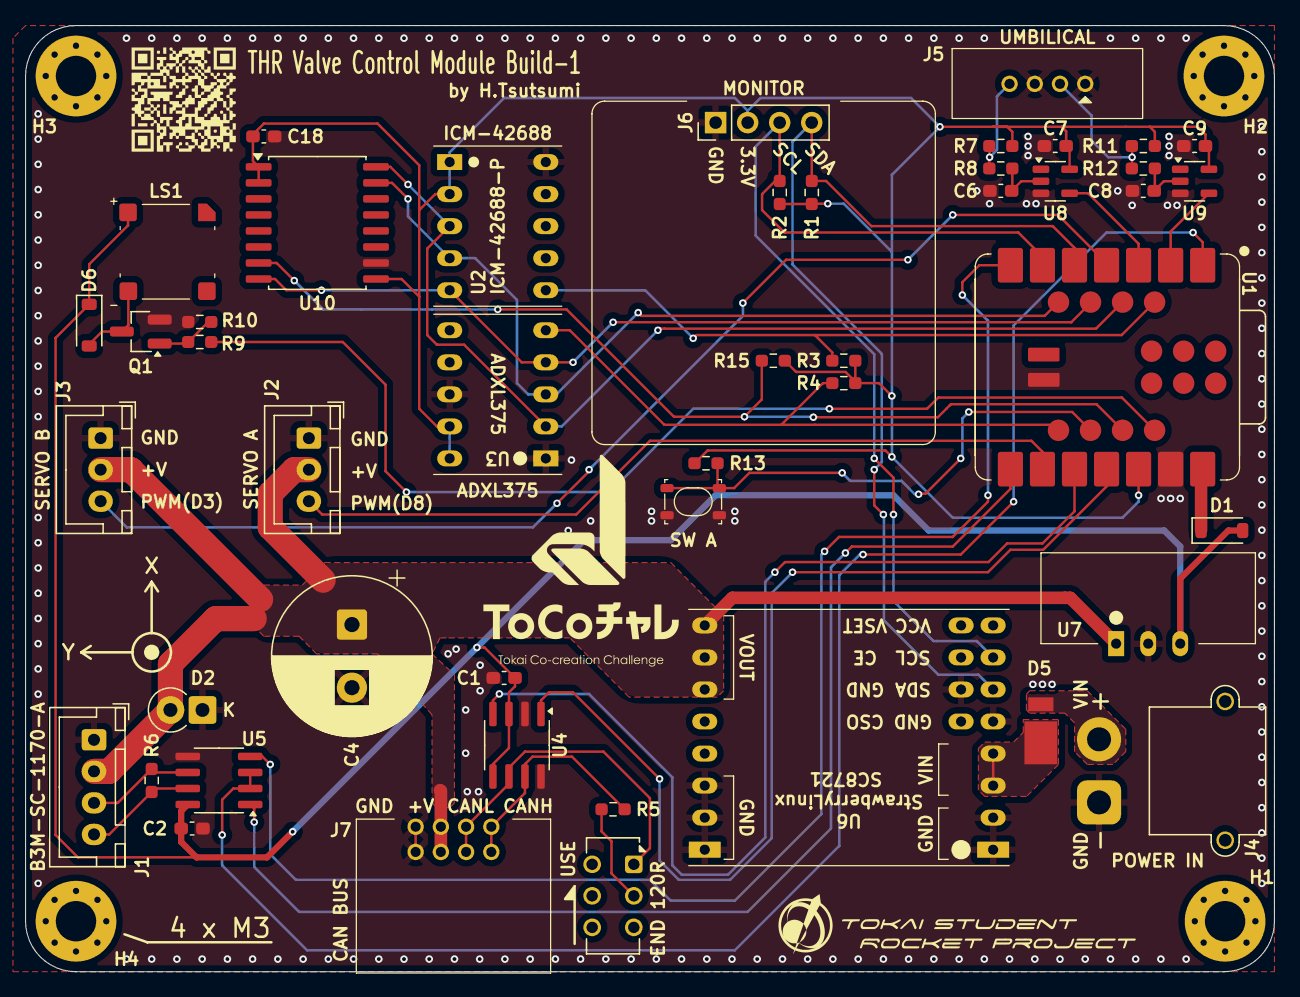
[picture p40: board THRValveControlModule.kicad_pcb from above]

Board: 2 copper layers, 99.0 x 75.0 mm, 51 parts (0 on the bottom side), 37 nets.

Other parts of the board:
END 120R: IS-2235; SW_CK_JS202011CQN_DPDT_Straight
SW A: SKRPACE010

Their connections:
CAN_L: END 120R.1 (A); also elsewhere on the board
GND: SW A.3 (K), SW A.4 (A); also elsewhere on the board
unnamed 17: END 120R.2 (B); also elsewhere on the board
Periferal_SwitchA: SW A.1, SW A.2; also elsewhere on the board

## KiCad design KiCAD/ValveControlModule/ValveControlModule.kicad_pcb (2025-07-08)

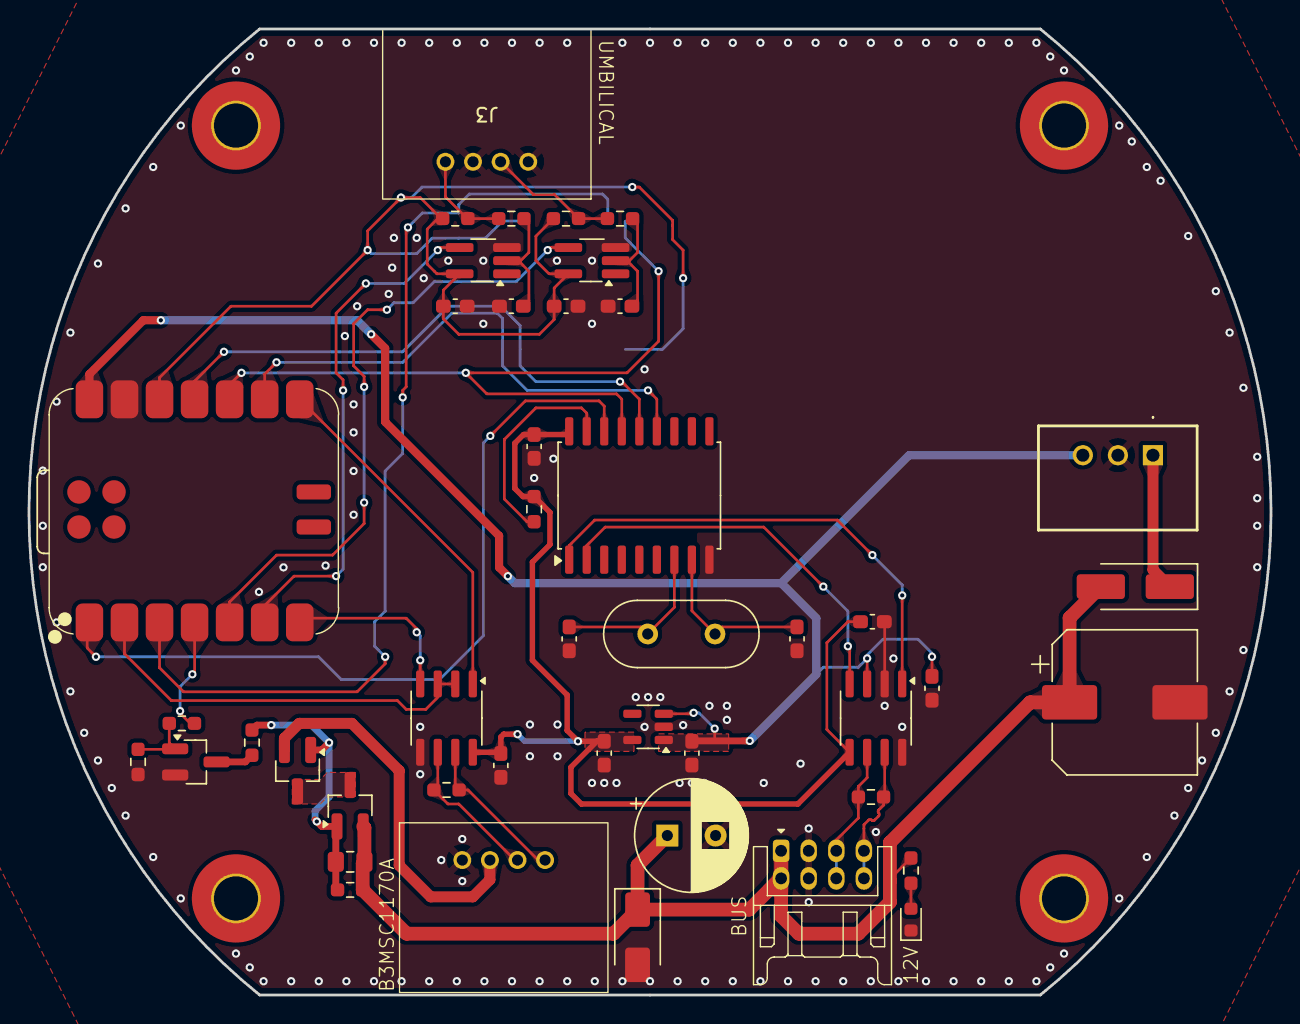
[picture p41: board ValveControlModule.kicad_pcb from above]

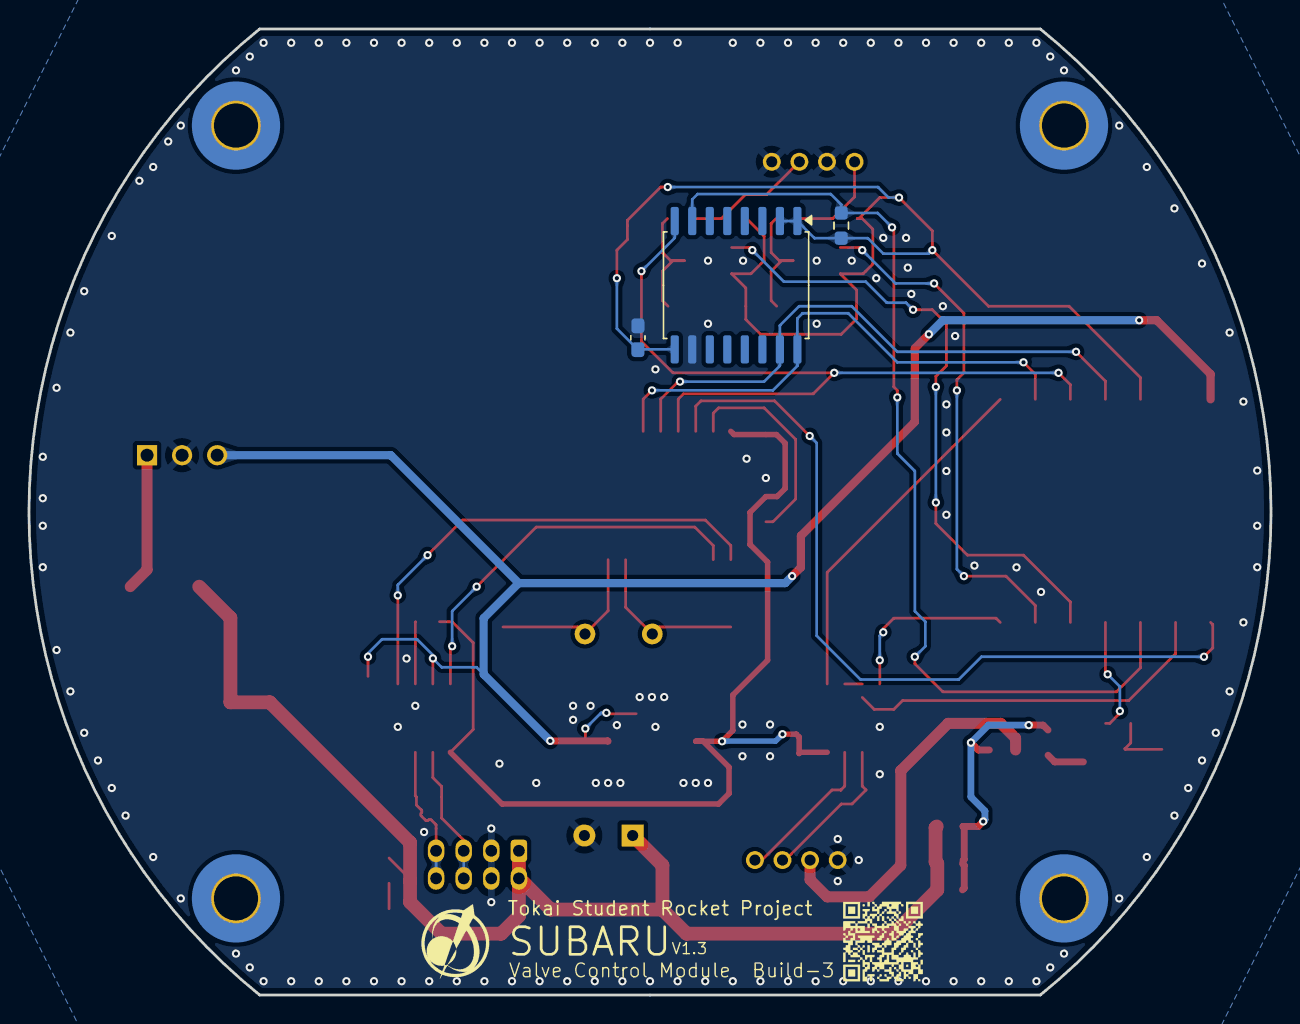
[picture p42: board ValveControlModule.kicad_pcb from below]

Board: 2 copper layers, 90.0 x 70.0 mm, 52 parts (3 on the bottom side), 36 nets.

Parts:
C1, C3, C4, C5, C11, C12, C13, C14, C18: 0.1uF; C_0603_1608Metric_Pad1.08x0.95mm_HandSolder
C6, C7: 15pF; C_0603_1608Metric_Pad1.08x0.95mm_HandSolder
C9, C10: 1uF; C_0603_1608Metric_Pad1.08x0.95mm_HandSolder
C15: 330uF; CP_Elec_10x10
C16: 100uF; CP_Radial_D8.0mm_P3.50mm
C17: 22uF; C_0805_2012Metric_Pad1.18x1.45mm_HandSolder
D1: SMAJ45A; D_SMA
D3: Green; LED_0603_1608Metric
D9: SB34AFC; D_SMA_Handsoldering
H1, H2, H3, H4: MountingHole_Pad; MountingHole_3.2mm_M3_Pad_TopBottom
J1, J3: DF51A-4P-2DS
J2: DF11-8DP-2DS
PS1: M78AR05-0.5; M78AR03305
Q2, Q4: AO3401A; SOT-23_Handsoldering
Q3: AO3400A; SOT-23_Handsoldering
R1, R6: 120; R_0603_1608Metric_Pad0.98x0.95mm_HandSolder
R4: 10K; R_0603_1608Metric_Pad0.98x0.95mm_HandSolder
R9: 4.7k; R_0603_1608Metric_Pad0.98x0.95mm_HandSolder
R10: 820R; R_0603_1608Metric_Pad0.98x0.95mm_HandSolder
R11: 2.4kR; R_0603_1608Metric_Pad0.98x0.95mm_HandSolder
R12, R14, R24, R25, R26, R27: 10kR; R_0603_1608Metric_Pad0.98x0.95mm_HandSolder
R13: 100kR; R_0603_1608Metric_Pad0.98x0.95mm_HandSolder
U1: XIAO-RP2040-DIP; XIAO-RP2040-SMD
U2: LT1785xS8; SOIC-8_3.9x4.9mm_P1.27mm
U3: MCP2515-xSO; SOIC-18W_7.5x11.6mm_P1.27mm
U4: MCP2562-E-SN; SOIC-8_3.9x4.9mm_P1.27mm
U5: NCV8114BSN330T1G; TSOT-23-5
U6: MB85RQ8MX; SOIC-16W_7.5x10.3mm_P1.27mm
U8, U9: TC7S14F; TSOT-23-5_HandSoldering
Y1: 8MHz; Crystal_HC49-4H_Vertical

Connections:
+3.3V: C1.2, C3.1, C5.2, C10.1, R4.2, U2.8 (VCC), U3.18 (VDD), U4.5 (Vio), U5.5 (OUT)
+3V3: C12.2, C14.2, C18.1, R9.1, R24.2, R26.2, U1.12 (3V3), U6.1 (~HOLD(IO3)), U6.2 (VDD), U6.9 (~WP(IO2)), U8.5 (VCC), U9.5 (VCC)
+5V: C4.2, C9.1, PS1.3 (+VOUT), U1.14 (VBUS), U4.3 (VDD), U5.1 (IN), U5.3 (EN)
+12V: C15.1, C16.1, C17.1, D1.1 (K), D9.2 (A), J2.1, J2.2, Q4.2 (S), R11.1, R12.1
CAN_H: J2.7, J2.8, R6.2, U4.7 (CANH)
CAN_L: J2.5, J2.6, R6.1, U4.6 (CANL)
CAN_RX: U3.2 (RXCAN), U4.4 (RXD)
CAN_TX: U3.1 (TXCAN), U4.1 (TXD)
GND: C1.1, C3.2, C4.1, C5.1, C6.2, C7.2, C9.2, C10.2, C11.1, C12.1, C13.1, C14.1, C15.2, C16.2, C18.2, D1.2 (A), D3.1 (K), J1.1, J2.3, J2.4, J3.1, J3.3, PS1.2 (GND), Q3.2 (S), R14.2, U1.13 (GND), U2.5 (GND), U3.9 (VSS), U4.2 (VSS), U4.8 (STBY), U5.2 (GND), U6.10 (VSS), U8.3 (GND), U9.3 (GND)
unnamed: C11.2, R25.2, U8.2
unnamed: C13.2, R27.2, U9.2
unnamed: D3.2 (A), R11.2
unnamed: D9.1 (K), PS1.1 (+VIN)
unnamed: J1.2, Q2.2 (S)
unnamed: J3.2, R26.1, R27.1
unnamed: J3.4, R24.1, R25.1
unnamed: Q2.3 (D), Q4.3 (D)
unnamed: C17.2, Q2.1 (G), Q4.1 (G), R12.2, R13.1
unnamed: Q3.3 (D), R13.2
unnamed: Q3.1 (G), R10.2, R14.1
unnamed: R4.1, U3.17 (~RESET)
OSC1: C6.1, U3.8 (OSC1), Y1.2
OSC2: C7.1, U3.7 (OSC2), Y1.1
RS485_A: J1.3, R1.1, U2.6 (A)
RS485_B: J1.4, R1.2, U2.7 (B)
RS485_DI: U1.7 (GPIO0/TX), U2.4 (DI)
RS485_EN: U1.2 (GPIO27/ADC1/A1), U2.2 (~RE), U2.3 (DE)
RS485_RO: U1.8 (GPIO1/RX), U2.1 (RO)
SPI_CS_MCP2515: U1.1 (GPIO26/ADC0/A0), U3.16 (~CS)
SPI_MISO: U1.10 (GPIO4/MISO), U3.15 (SO), U6.8 (SO(IO1))
SPI_MOSI: U1.11 (GPIO3/MOSI), U3.14 (SI), U6.15 (SI(IO0))
SPI_SCK: U1.9 (GPIO2/SCK), U3.13 (SCK), U6.16 (SCK)
SPI_~CS_FeRAM0: R9.2, U1.3 (GPIO28/ADC2/A2), U6.7 (~CS)
ServoPower_EN: R10.1, U1.4 (GPIO29/ADC3/A3)
Umbilical_GseIgnition: U1.6 (GPIO7/SCL), U8.4
Umbilical_GseValve: U1.5 (GPIO6/SDA), U9.4

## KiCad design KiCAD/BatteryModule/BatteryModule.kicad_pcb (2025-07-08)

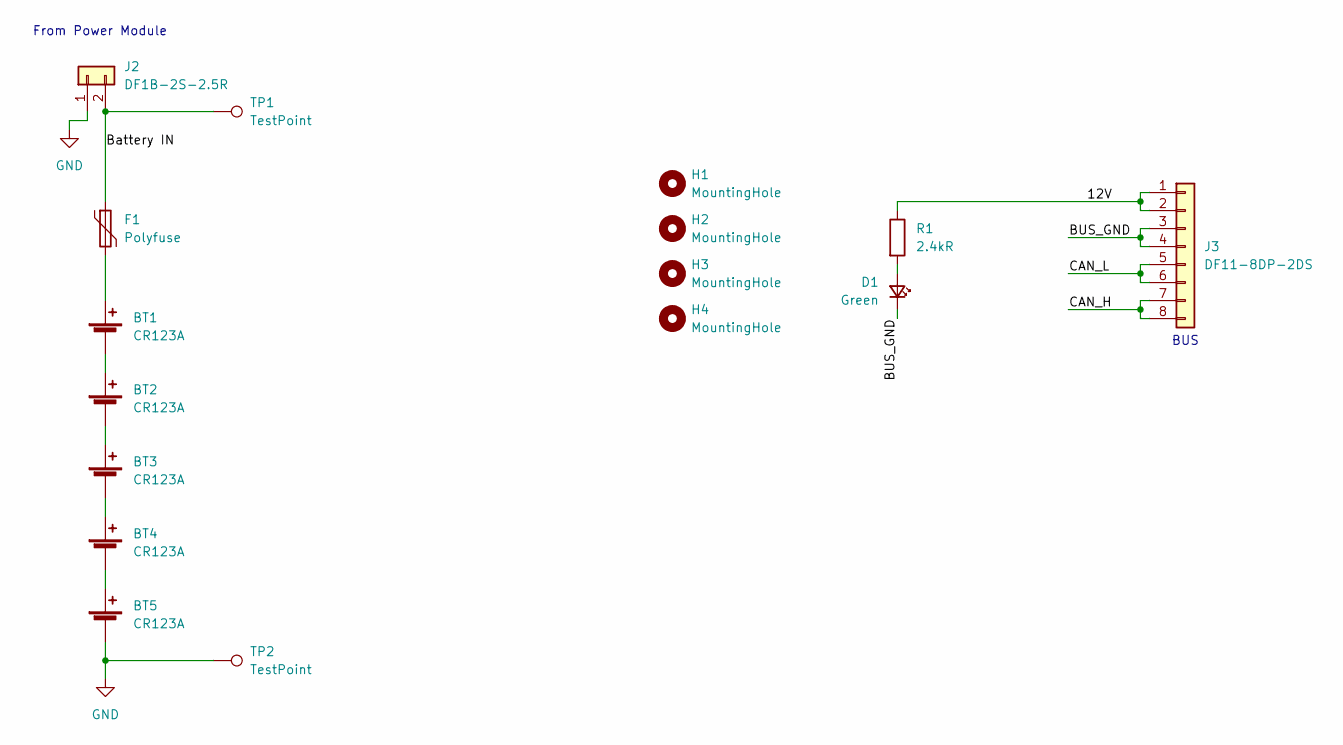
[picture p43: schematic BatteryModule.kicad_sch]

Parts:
BT1, BT2, BT3, BT4, BT5: CR123A; BHC-CR123A
D1: Green; LED_0603_1608Metric_Pad1.05x0.95mm_HandSolder
F1: Polyfuse; Fuse_Bourns_MF-RHT300
H1, H2, H3, H4: MountingHole; MountingHole_3.2mm_M3_Pad_TopBottom
J2: DF1B-2S-2.5R
J3: DF11-8DP-2DS
R1: 2.4kR; R_0603_1608Metric_Pad0.98x0.95mm_HandSolder
TP1, TP2: TestPoint; TestPoint_THTPad_D2.0mm_Drill1.0mm

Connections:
/12V: J3.1, J3.2, R1.1
/BUS_GND: D1.1 (K), J3.3, J3.4
/Battery IN: F1.1, J2.2, TP1.1
/CAN_H: J3.7, J3.8
/CAN_L: J3.5, J3.6
GND: BT5.2 (-), J2.1, TP2.1
unnamed: BT1.1 (+), F1.2
unnamed: BT1.2 (-), BT2.1 (+)
unnamed: BT2.2 (-), BT3.1 (+)
unnamed: BT3.2 (-), BT4.1 (+)
unnamed: BT4.2 (-), BT5.1 (+)
unnamed: D1.2 (A), R1.2

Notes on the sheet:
BUS
From Power Module

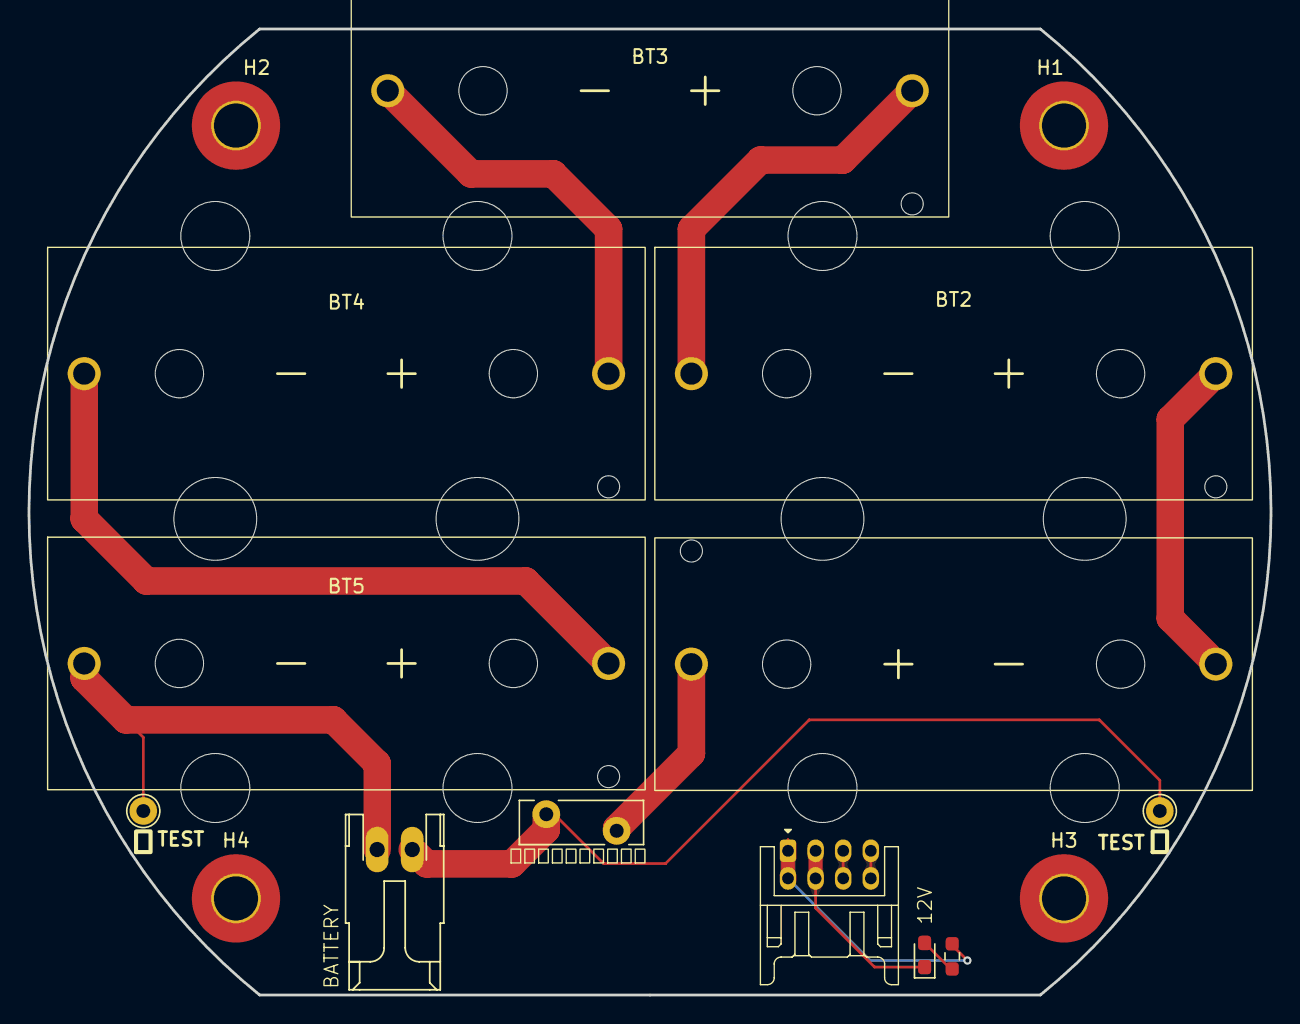
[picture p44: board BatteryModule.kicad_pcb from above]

Board: 2 copper layers, 90.0 x 70.0 mm, 16 parts (0 on the bottom side), 12 nets.

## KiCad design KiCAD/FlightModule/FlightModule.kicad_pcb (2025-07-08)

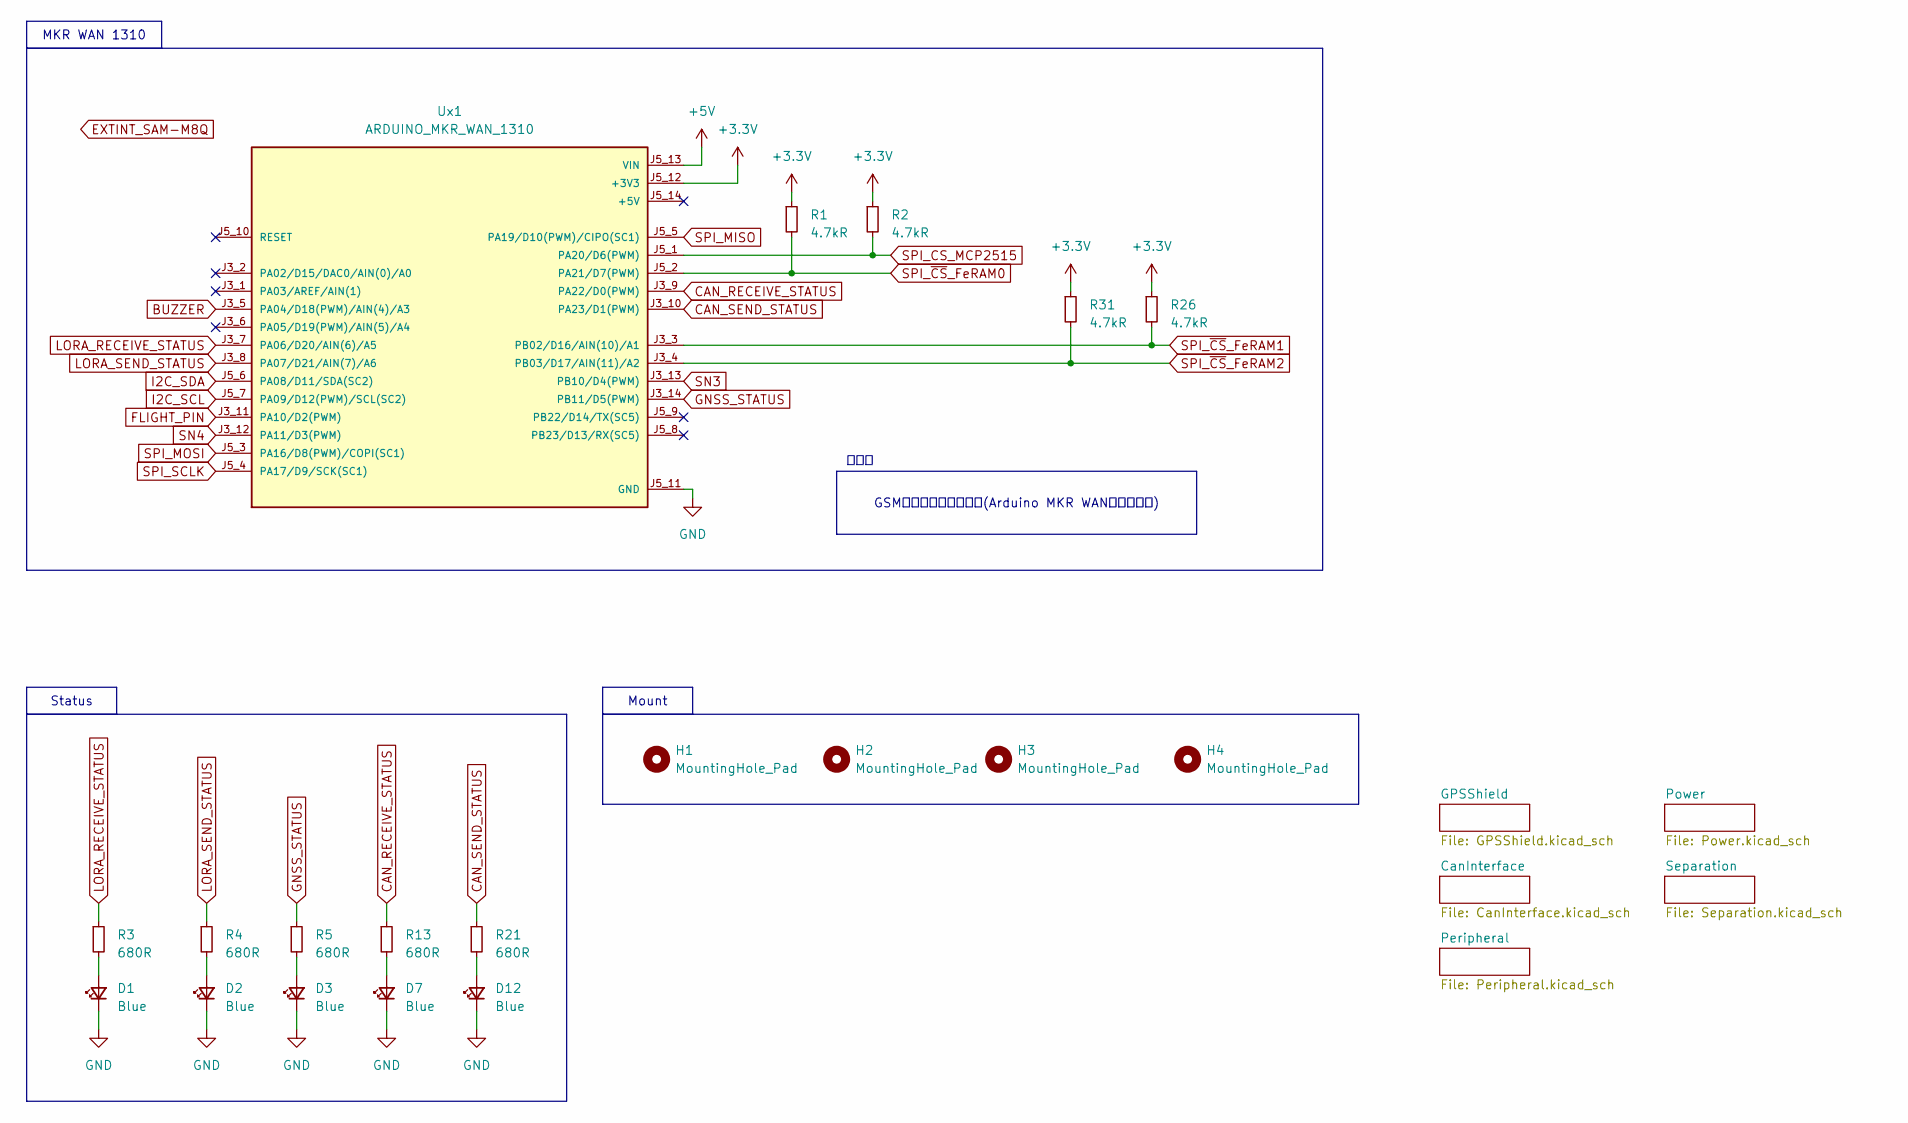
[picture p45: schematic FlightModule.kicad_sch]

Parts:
D1, D2, D3, D7, D12: Blue; LED_0603_1608Metric_Pad1.05x0.95mm_HandSolder
H1, H2, H3, H4: MountingHole_Pad; MountingHole_3.2mm_M3_Pad_TopBottom
R1, R2, R26, R31: 4.7kR; R_0603_1608Metric_Pad0.98x0.95mm_HandSolder
R3, R4, R5, R13, R21: 680R; R_0603_1608Metric_Pad0.98x0.95mm_HandSolder
Ux1: ARDUINO_MKR_WAN_1310; BOARD_ARDUINO_MKR_WAN_1310; PARTREV 06/27/2019

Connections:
+3.3V: R1.1, R2.1, R26.1, R31.1, Ux1.J5_12 (+3V3); also elsewhere on the board
+5V: Ux1.J5_13 (VIN); also elsewhere on the board
BUZZER: Ux1.J3_5 (PA04/D18(PWM)/AIN(4)/A3); also elsewhere on the board
CAN_RECEIVE_STATUS: R13.1, Ux1.J3_9 (PA22/D0(PWM))
CAN_SEND_STATUS: R21.1, Ux1.J3_10 (PA23/D1(PWM))
FLIGHT_PIN: Ux1.J3_11 (PA10/D2(PWM)); also elsewhere on the board
GND: D1.1 (K), D2.1 (K), D3.1 (K), D7.1 (K), D12.1 (K), Ux1.J5_11 (GND); also elsewhere on the board
GNSS_STATUS: R5.1, Ux1.J3_14 (PB11/D5(PWM))
I2C_SCL: Ux1.J5_7 (PA09/D12(PWM)/SCL(SC2)); also elsewhere on the board
I2C_SDA: Ux1.J5_6 (PA08/D11/SDA(SC2)); also elsewhere on the board
LORA_RECEIVE_STATUS: R3.1, Ux1.J3_7 (PA06/D20/AIN(6)/A5)
LORA_SEND_STATUS: R4.1, Ux1.J3_8 (PA07/D21/AIN(7)/A6)
unnamed: D1.2 (A), R3.2
unnamed: D2.2 (A), R4.2
unnamed: D3.2 (A), R5.2
unnamed: D7.2 (A), R13.2
unnamed: D12.2 (A), R21.2
SN3: Ux1.J3_13 (PB10/D4(PWM)); also elsewhere on the board
SN4: Ux1.J3_12 (PA11/D3(PWM)); also elsewhere on the board
SPI_CS_MCP2515: R2.2, Ux1.J5_1 (PA20/D6(PWM)); also elsewhere on the board
SPI_MISO: Ux1.J5_5 (PA19/D10(PWM)/CIPO(SC1)); also elsewhere on the board
SPI_MOSI: Ux1.J5_3 (PA16/D8(PWM)/COPI(SC1)); also elsewhere on the board
SPI_SCLK: Ux1.J5_4 (PA17/D9/SCK(SC1)); also elsewhere on the board
SPI_~CS_FeRAM0: R1.2, Ux1.J5_2 (PA21/D7(PWM)); also elsewhere on the board
SPI_~CS_FeRAM1: R26.2, Ux1.J3_3 (PB02/D16/AIN(10)/A1); also elsewhere on the board
SPI_~CS_FeRAM2: R31.2, Ux1.J3_4 (PB03/D17/AIN(11)/A2); also elsewhere on the board

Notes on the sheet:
付属品
GSMダイポールアンテナ(Arduino MKR WAN用アンテナ)
Mount
MKR WAN 1310
Status


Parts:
C1: 330uF; CP_Elec_10x10
C10, C11: 1uF; C_0805_2012Metric_Pad1.18x1.45mm_HandSolder
D4: Green; LED_0603_1608Metric_Pad1.05x0.95mm_HandSolder
D5: GS1010FL; D_SOD-123F
PS1: M78AR05-0.5; M78AR03305; Manufacturer_Part_Number M78AR05-0.5
R6: 2.4kR; R_0603_1608Metric_Pad0.98x0.95mm_HandSolder
U5: NCV8114BSN330T1G; TSOT-23-5

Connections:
+3.3V: C11.1, U5.5 (OUT); also elsewhere on the board
+5V: C10.1, PS1.3 (+VOUT), U5.1 (IN), U5.3 (EN); also elsewhere on the board
+12V: C1.1, D5.2 (A), R6.1; also elsewhere on the board
GND: C1.2, C10.2, C11.2, D4.1 (K), PS1.2 (GND), U5.2 (GND); also elsewhere on the board
unnamed: D4.2 (A), R6.2
unnamed: D5.1 (K), PS1.1 (+VIN)

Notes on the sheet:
本当は RT9080-33GJ5
Power Good
Linear Regulator
Switching Regulator
To MCU
From BUS
From DCDC


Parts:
C4, C5, C13: 0.1uF; C_0603_1608Metric_Pad1.08x0.95mm_HandSolder
C6, C7: 15pF; C_0603_1608Metric_Pad1.08x0.95mm_HandSolder
J1: DF11B-8DP-2DS; DF11-8DP-2DS
R11: 120R; R_0603_1608Metric_Pad0.98x0.95mm_HandSolder
R14: 10kR; R_0603_1608Metric_Pad0.98x0.95mm_HandSolder
U8: MCP2562-E-SN; SOIC-8_3.9x4.9mm_P1.27mm
U9: MCP2515-xST; TSSOP-20_4.4x6.5mm_P0.65mm
Y1: 8MHz; Crystal_SMD_HC49-SD

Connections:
+3.3V: C4.2, C5.2, R14.2, U8.5 (Vio), U9.20 (VDD); also elsewhere on the board
+5V: C13.2, U8.3 (VDD); also elsewhere on the board
+12V: J1.1, J1.2; also elsewhere on the board
CAN_H: J1.7, J1.8, R11.1, U8.7 (CANH)
CAN_L: J1.5, J1.6, R11.2, U8.6 (CANL)
CAN_RX: U8.4 (RXD), U9.2 (RXCAN)
CAN_TX: U8.1 (TXD), U9.1 (TXCAN)
GND: C4.1, C5.1, C6.2, C7.2, C13.1, J1.3, J1.4, U8.2 (VSS), U8.8 (STBY), U9.10 (VSS); also elsewhere on the board
unnamed: R14.1, U9.19 (~RESET)
OSC1: C6.1, U9.9 (OSC1), Y1.2
OSC2: C7.1, U9.8 (OSC2), Y1.1
SPI_CS_MCP2515: U9.18 (~CS); also elsewhere on the board
SPI_MISO: U9.17 (SO); also elsewhere on the board
SPI_MOSI: U9.16 (SI); also elsewhere on the board
SPI_SCLK: U9.14 (SCK); also elsewhere on the board

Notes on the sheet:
BUS：CAN + 電源ライン
組み立て位置により終端抵抗の 取り付けを有無を決めること
CANコントローラー
CANトランシーバー


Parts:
C16, C17: 1uF; C_0805_2012Metric_Pad1.18x1.45mm_HandSolder
R27: 100kR; R_0603_1608Metric_Pad0.98x0.95mm_HandSolder
R28: 0R; R_0603_1608Metric_Pad0.98x0.95mm_HandSolder
R29, R30: 4.7kR; R_0603_1608Metric_Pad0.98x0.95mm_HandSolder
U3: SAM-M8Q-0-10; MODULE_SAM-M8Q-0-10; PARTREV R07

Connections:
+3.3V: C16.1, C17.1, R27.1, R28.1, R29.1, R30.1, U3.2 (VCC_IO), U3.17 (VCC); also elsewhere on the board
EXTINT_SAM-M8Q: U3.19 (EXTINT0)
GND: C16.2, C17.2, U3.1 (GND), U3.4 (GND), U3.5 (GND), U3.6 (GND), U3.10 (GND), U3.11 (GND), U3.15 (GND), U3.16 (GND), U3.20 (GND); also elsewhere on the board
I2C_SCL: R29.2, U3.12 (SCL); also elsewhere on the board
I2C_SDA: R30.2, U3.9 (SDA); also elsewhere on the board
unnamed: R28.2, U3.3 (V_BCKP)
UART_RXD: R27.2, U3.14 (RXD)
UART_TXD: U3.13 (TXD)

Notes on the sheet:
ジャンパ抵抗
GNSS


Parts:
BZ1: UGCM1205XP; Buzzer_12x9.5RM7.6
C8, C9, C14, C15, C18: 0.1uF; C_0603_1608Metric_Pad1.08x0.95mm_HandSolder
J4: DF51-2P-2DS
Q3: 2SC3325-Y; SC-59_Handsoldering
R22: 4.7kR; R_0603_1608Metric_Pad0.98x0.95mm_HandSolder
R23, R24, R25: 10kR; R_0603_1608Metric_Pad0.98x0.95mm_HandSolder
U1, U2, U4: MB85RQ8MX; SOIC-16W_7.5x10.3mm_P1.27mm
U7: TC7S14F; TSOT-23-5_HandSoldering

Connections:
+3.3V: C9.2, C14.1, C15.1, C18.1, R24.2, U1.1 (~HOLD(IO3)), U1.2 (VDD), U1.9 (~WP(IO2)), U2.1 (~HOLD(IO3)), U2.2 (VDD), U2.9 (~WP(IO2)), U4.1 (~HOLD(IO3)), U4.2 (VDD), U4.9 (~WP(IO2)), U7.5 (VCC); also elsewhere on the board
+5V: BZ1.1 (-); also elsewhere on the board
BUZZER: R22.1; also elsewhere on the board
FLIGHT_PIN: U7.4; also elsewhere on the board
GND: C8.1, C9.1, C14.2, C15.2, C18.2, J4.1, Q3.2 (E), R23.1, U1.10 (VSS), U2.10 (VSS), U4.10 (VSS), U7.3 (GND); also elsewhere on the board
unnamed: BZ1.2 (+), Q3.3 (C)
unnamed: C8.2, R25.2, U7.2
unnamed: J4.2, R24.1, R25.1
unnamed: Q3.1 (B), R22.2, R23.2
SPI_MISO: U1.8 (SO(IO1)), U2.8 (SO(IO1)), U4.8 (SO(IO1)); also elsewhere on the board
SPI_MOSI: U1.15 (SI(IO0)), U2.15 (SI(IO0)), U4.15 (SI(IO0)); also elsewhere on the board
SPI_SCLK: U1.16 (SCK), U2.16 (SCK), U4.16 (SCK); also elsewhere on the board
SPI_~CS_FeRAM0: U1.7 (~CS); also elsewhere on the board
SPI_~CS_FeRAM1: U2.7 (~CS); also elsewhere on the board
SPI_~CS_FeRAM2: U4.7 (~CS); also elsewhere on the board

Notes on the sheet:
現在の状態を把握するため
FeRAM2
FeRAM0
FeRAM1
ブザー
フライトピン


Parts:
D8, D10: Green; LED_0603_1608Metric_Pad1.05x0.95mm_HandSolder
D9, D11: GS1010FL; D_SOD-123F
J5: DF51A-4P-2DSA
Q1, Q2: AO3400A; SOT-23
R15, R18: 300R; R_0603_1608Metric_Pad0.98x0.95mm_HandSolder
R16, R19: 10kR; R_0603_1608Metric_Pad0.98x0.95mm_HandSolder
R17, R20: 2.4kR; R_0603_1608Metric_Pad0.98x0.95mm_HandSolder

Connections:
+12V: D9.1 (K), D11.1 (K), J5.2, J5.4, R17.1, R20.1; also elsewhere on the board
GND: Q1.2 (S), Q2.2 (S), R16.1, R19.1; also elsewhere on the board
unnamed: D8.2 (A), R17.2
unnamed: D8.1 (K), D9.2 (A), J5.3, Q1.3 (D)
unnamed: D10.2 (A), R20.2
unnamed: D10.1 (K), D11.2 (A), J5.1, Q2.3 (D)
unnamed: Q1.1 (G), R15.2, R16.2
unnamed: Q2.1 (G), R18.2, R19.2
SN3: R15.1; also elsewhere on the board
SN4: R18.1; also elsewhere on the board

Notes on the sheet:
12V ラインをMOSFETにより駆動
SN4
SN3



Board: 2 copper layers, 90.0 x 70.0 mm, 74 parts (19 on the bottom side), 48 nets.

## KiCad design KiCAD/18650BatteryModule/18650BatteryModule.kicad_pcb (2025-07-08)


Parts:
BT1, BT2, BT3, BT4: 1042; BAT_1042; PARTREV E
D1: Green; LED_0603_1608Metric_Pad1.05x0.95mm_HandSolder
F1: Polyfuse; Fuse_Bourns_MF-RHT300
H1, H2, H3, H4: MountingHole; MountingHole_3.2mm_M3_Pad_TopBottom
J1: DF1B-2S-2.5R
J2: DF11-8DP-2DS
R1: 2.4kR; R_0603_1608Metric_Pad0.98x0.95mm_HandSolder
TP1: TestPoint; TestPoint_THTPad_D1.0mm_Drill0.5mm
TP2: TestPoint_GND; TestPoint_THTPad_1.0x1.0mm_Drill0.5mm

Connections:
/12V: J2.1, J2.2, R1.1
/BUS_GND: D1.1 (K), J2.3, J2.4
/CAN_H: J2.7, J2.8
/CAN_L: J2.5, J2.6
GND: BT4.N, J1.1, TP2.1
unnamed: BT1.N, BT2.P
unnamed: BT1.P, F1.2
unnamed: BT2.N, BT3.P
unnamed: BT3.N, BT4.P
unnamed: D1.2 (A), R1.2
unnamed: F1.1, J1.2, TP1.1

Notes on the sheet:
From Power Module
BUS



Board: 2 copper layers, 94.0 x 70.0 mm, 15 parts (2 on the bottom side), 11 nets.

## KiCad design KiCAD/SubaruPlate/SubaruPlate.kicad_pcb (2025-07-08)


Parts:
H1, H2, H3, H4: MountingHole; MountingHole_3.2mm_M3_Pad_TopBottom

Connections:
GND: H1.1, H2.1, H3.1, H4.1; also elsewhere on the board

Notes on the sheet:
M3 Mount


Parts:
C1, C14: 10uF; C_0603_1608Metric_Pad1.08x0.95mm_HandSolder
C2, C13: 0.1uF; C_0603_1608Metric_Pad1.08x0.95mm_HandSolder
J1: Wire_Soldering; PinHeader_1x04_P1.27mm_Vertical
R1, R2, R3, R14, R16: 10kR; R_0603_1608Metric_Pad0.98x0.95mm_HandSolder
U1, U6: LPS28DFW; CCLGA-7L

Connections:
+3.3V: C1.1, C2.1, C13.1, C14.1, J1.2, R2.1, R3.1, R14.1, R16.1, U1.6 (VDD), U6.2 (SA0), U6.6 (VDD)
GND: C1.2, C2.2, C13.2, C14.2, J1.1, R1.2, U1.5 (GND), U1.7 (LID), U6.5 (GND), U6.7 (LID); also elsewhere on the board
I2C_SCL: J1.4, R3.2, R16.2, U1.3 (SCL), U6.3 (SCL)
I2C_SDA: J1.3, R2.2, R14.2, U1.1 (SDA), U6.1 (SDA)
unnamed: R1.1, U1.2 (SA0)

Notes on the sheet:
I2C Address: 0x5D
I2C Address: 0x5C
データシート LPS28DFW
Adafruit LPS28
STマイクロ LPS28DFW
気圧センサー
I2C バス
参考資料

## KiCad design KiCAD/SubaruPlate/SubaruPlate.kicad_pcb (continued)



Board: 2 copper layers, 140.0 x 140.0 mm, 16 parts (2 on the bottom side), 5 nets.

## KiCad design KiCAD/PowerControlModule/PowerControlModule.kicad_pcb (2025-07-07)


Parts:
H1, H2, H3, H4: MountingHole; MountingHole_3.2mm_M3_Pad_TopBottom

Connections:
GND: H1.1, H2.1, H3.1, H4.1; also elsewhere on the board

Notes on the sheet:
マウント


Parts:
C13, C16, C17: 0.1uF; C_0603_1608Metric_Pad1.08x0.95mm_HandSolder
C14, C15: 15pF; C_0603_1608Metric_Pad1.08x0.95mm_HandSolder
C19, C20: 2.2uF; C_0603_1608Metric_Pad1.08x0.95mm_HandSolder
D3: Green; LED_0603_1608Metric_Pad1.05x0.95mm_HandSolder
D5: SMAJ45A; D_SMA
D10: SS2040FL; D_SOD-123F
J3: DF11-8DP-2DS
R21: 3.6kR; R_0603_1608Metric_Pad0.98x0.95mm_HandSolder
R24: 10kR; R_0603_1608Metric_Pad0.98x0.95mm_HandSolder
R25: 120R; R_0603_1608Metric_Pad0.98x0.95mm_HandSolder
U2: MCP2515-xST; TSSOP-20_4.4x6.5mm_P0.65mm
U8: MCP2562-E-SN; SOIC-8_3.9x4.9mm_P1.27mm
U9: MCP1792x-5002xCB; SOT-23_Handsoldering
Y1: 8MHz; Crystal_HC49-4H_Vertical

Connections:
+3.3V: C13.1, C16.2, R24.2, U2.20 (VDD), U8.5 (Vio); also elsewhere on the board
+5VD: C17.2, C20.1, D10.2 (A), U8.3 (VDD), U9.2 (VO)
+12V: C19.1, D5.1 (K), D10.1 (K), J3.1, J3.2, R21.1, U9.3 (VI); also elsewhere on the board
CAN_H: J3.7, J3.8, R25.2, U8.7 (CANH)
CAN_L: J3.5, J3.6, R25.1, U8.6 (CANL)
CAN_RX: U2.2 (RXCAN), U8.4 (RXD)
CAN_TX: U2.1 (TXCAN), U8.1 (TXD)
GND: C13.2, C14.2, C15.2, C16.1, C17.1, C19.2, C20.2, D3.1 (K), D5.2 (A), J3.3, J3.4, U2.10 (VSS), U8.2 (VSS), U8.8 (STBY), U9.1 (GND); also elsewhere on the board
unnamed: D3.2 (A), R21.2
unnamed: R24.1, U2.19 (~RESET)
OSC1: C14.1, U2.9 (OSC1), Y1.2
OSC2: C15.1, U2.8 (OSC2), Y1.1
SPI_CS_MCP2515: U2.18 (~CS); also elsewhere on the board
SPI_MISO: U2.17 (SO); also elsewhere on the board
SPI_MOSI: U2.16 (SI); also elsewhere on the board
SPI_SCK: U2.14 (SCK); also elsewhere on the board

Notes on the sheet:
終端抵抗．モジュールに応じて取り付ける．
CANトランシーバー
CAN バス
CANコントローラー


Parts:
C1: 220uF; CP_Radial_D6.3mm_P2.50mm
C2, C4: 22uF; C_0805_2012Metric_Pad1.18x1.45mm_HandSolder
C3, C5, C22: 0.1uF; C_0603_1608Metric_Pad1.08x0.95mm_HandSolder
C9: 2200uF; CP_Radial_D18.0mm_P7.50mm
C10: 0.1uF; C_0603_1608Metric
C11: 33uF; CP_Elec_6.3x5.9
C18, C21: 0.056uF; L_0603_1608Metric
D1, D2: Orange; LED_0603_1608Metric_Pad1.05x0.95mm_HandSolder
D4: SMAJ45A; D_SMA
D7, D8, D9: Red; LED_0603_1608Metric_Pad1.05x0.95mm_HandSolder
J1, J2: DF1B-2S-2.5R
Q1, Q2, Q4, Q5, Q7, Q9: AO3401A; SOT-23_Handsoldering
Q3: AO3400A; TSOT-23_HandSoldering
Q6, Q10: AO3401A; SOT-23; not fitted
Q11, Q12: Si4162DY; SOIC-8_3.9x4.9mm_P1.27mm
R3, R6, R7, R22, R26: 10kR; R_0603_1608Metric_Pad0.98x0.95mm_HandSolder
R4, R18, R19: 5.6kR; R_0603_1608Metric_Pad0.98x0.95mm_HandSolder
R5, R20: 3.3kR; R_0603_1608Metric_Pad0.98x0.95mm_HandSolder
R8: 4.7kR; R_0603_1608Metric_Pad0.98x0.95mm_HandSolder
R9, R13, R14: 680R; R_0603_1608Metric_Pad0.98x0.95mm_HandSolder
R10, R11, R12: 15mR; R_2512_6332Metric_Pad1.40x3.35mm_HandSolder
R15, R16: 2.7kR; R_0603_1608Metric_Pad0.98x0.95mm_HandSolder
R17: 820; R_0603_1608Metric_Pad0.98x0.95mm_HandSolder
R27: 10k; R_0603_1608Metric
TH1: Thermistor_NTC; PinHeader_1x02_P2.00mm_Vertical
U3, U4, U6: INA228; VSSOP-10_3x3mm_P0.5mm
U5: LTC4353; MSOP-16_3x4.039mm_P0.5mm
U11: LTC3119; StrawberryLinux_LTC3119

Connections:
+3.3V: C3.1, C5.1, C22.1, D7.2 (A), D8.2 (A), D9.2 (A), R26.1, R27.1, U3.6 (VS), U4.2 (A0), U4.6 (VS), U6.1 (A1), U6.2 (A0), U6.6 (VS); also elsewhere on the board
+12V: R12.2, U6.9 (Vin-); also elsewhere on the board
+VSW: Q7.2 (S), U11.12 (VIN), U11.13 (VIN), U11.14 (RUN)
/PowerControl/BATT: C2.1, J2.2, Q2.2 (S), R4.1
/PowerControl/BATT_LOWER: C21.2, Q12.1 (S), Q12.2 (S), Q12.3 (S), R11.1, U4.9 (Vin-), U5.4 (VIN2)
/PowerControl/BATT_UPPER: Q4.2 (S), R11.2, U4.8 (Vbus), U4.10 (Vin+)
/PowerControl/BUS_LOWER: C1.1, R12.1, U6.8 (Vbus), U6.10 (Vin+), U11.3 (VOUT), U11.4 (VOUT)
/PowerControl/GPU: C4.1, J1.2, Q5.2 (S), R7.1
/PowerControl/GPU_LOWER: C18.2, Q11.1 (S), Q11.2 (S), Q11.3 (S), R10.2, U3.9 (Vin-), U5.13 (VIN1)
/PowerControl/GPU_UPPER: Q9.2 (S), R10.1, U3.8 (Vbus), U3.10 (Vin+)
BATT_EN: R17.1; also elsewhere on the board
GND: C1.2, C3.2, C5.2, C9.2, C10.2, C22.2, J1.1, J2.1, Q3.2 (S), R3.2, R6.2, R8.2, R20.2, R22.2, TH1.2, U3.1 (A1), U3.2 (A0), U3.7 (GND), U4.1 (A1), U4.7 (GND), U5.15 (GND), U6.7 (GND), U11.1 (GND), U11.5 (GND), U11.6 (GND), U11.9 (GND), U11.10 (GND), U11.11 (GND), U11.16 (GND); also elsewhere on the board
I2C_SCL: U3.5 (SCL), U4.5 (SCL), U6.5 (SCL); also elsewhere on the board
I2C_SDA: U3.4 (SDA), U4.4 (SDA), U6.4 (SDA); also elsewhere on the board
LTC3119_PGOOD: R27.2, U11.2 (PGOOD); also elsewhere on the board
LTC4353_EN1: R3.1, U5.16 (EN1); also elsewhere on the board
LTC4353_EN2: R6.1, U5.1 (EN2); also elsewhere on the board
unnamed: D1.2 (A), R15.1
unnamed: D1.1 (K), U5.9 (ONST1)
unnamed: D2.2 (A), R16.1
unnamed: D2.1 (K), U5.8 (ONST1)
unnamed: C9.1, D4.2 (A), R18.1
unnamed: C11.1, D4.1 (K), Q1.2 (S), Q11.5 (D), Q11.6 (D), Q11.7 (D), Q11.8 (D), Q12.5 (D), Q12.6 (D), Q12.7 (D), Q12.8 (D), R15.2, R16.2, R18.2, R19.1, U5.7 (OUT2), U5.10 (OUT1)
unnamed: D7.1 (K), R9.1
unnamed: D8.1 (K), R13.1
unnamed: D9.1 (K), R14.1
unnamed: Q1.3 (D), Q7.3 (D)
unnamed: C11.2, Q1.1 (G), Q7.1 (G), R19.2, R20.1
unnamed: Q2.3 (D), Q4.3 (D)
unnamed: C2.2, Q2.1 (G), Q4.1 (G), R4.2, R5.1
unnamed: Q3.3 (D), R5.2
unnamed: Q3.1 (G), R17.2, R22.1
unnamed: Q5.3 (D), Q9.3 (D)
unnamed: C4.2, Q5.1 (G), Q9.1 (G), R7.2, R8.1
unnamed: Q11.4 (G), U5.12 (GATE1)
unnamed: Q12.4 (G), U5.5 (GATE2)
unnamed: R14.2, U3.3 (~Alert)
unnamed: R13.2, U4.3 (~Alert)
unnamed: C18.1, U5.11 (CPO1)
unnamed: C21.1, U5.6 (CPO2)
unnamed: C10.1, U5.14 (VCC)
unnamed: R9.2, U6.3 (~Alert)
unnamed: U11.7 (VCC), U11.8 (MPPC), U11.15 (PWM/SYNC)
VREF_T1: R26.2, TH1.1; also elsewhere on the board

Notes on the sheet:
SLAVE ADDRESS: 0b1000000
逆流防止ロードスイッチ
今までの接続 H-59 H-60
From Ground Power Unit [GPU] (External)
SLAVE ADDRESS: 0b100 0001
17V
15Vくらい
AO3401A
SLAVE ADDRESS: 100 0101
2:S
3:D
Pch MOSFET
From Battery Module (Internal)
1:G
R7, R8 で分圧して5.5Vくらい
0.015 ohm 1% 3W 電流検出抵抗
R4, R5 で分圧して5.5Vくらい
ソースとドレインのピン番号が反対で接続されていた


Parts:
D11: SS2040FL; D_SOD-123F
R1, R2, R23: 4.7kR; R_0603_1608Metric_Pad0.98x0.95mm_HandSolder
U1: XIAO-RP2040-DIP; XIAO-RP2040-SMD

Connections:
+3.3V: R1.1, R2.1, R23.1, U1.12 (3V3); also elsewhere on the board
+5V: D11.2 (A); also elsewhere on the board
BATT_EN: U1.7 (GPIO0/TX); also elsewhere on the board
GND: U1.13 (GND); also elsewhere on the board
I2C_SCL: R2.2, U1.6 (GPIO7/SCL); also elsewhere on the board
I2C_SDA: R1.2, U1.5 (GPIO6/SDA); also elsewhere on the board
LTC3119_PGOOD: U1.8 (GPIO1/RX); also elsewhere on the board
LTC4353_EN1: U1.3 (GPIO28/ADC2/A2); also elsewhere on the board
LTC4353_EN2: U1.4 (GPIO29/ADC3/A3); also elsewhere on the board
unnamed: D11.1 (K), U1.14 (VBUS)
SPI_CS_MCP2515: R23.2, U1.1 (GPIO26/ADC0/A0); also elsewhere on the board
SPI_MISO: U1.10 (GPIO4/MISO); also elsewhere on the board
SPI_MOSI: U1.11 (GPIO3/MOSI); also elsewhere on the board
SPI_SCK: U1.9 (GPIO2/SCK); also elsewhere on the board
VREF_T1: U1.2 (GPIO27/ADC1/A1); also elsewhere on the board


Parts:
D6: SS2040FL; D_SOD-123F
PS1: M78AR05-0.5; M78AR03305; Manufacturer_Part_Number M78AR05-0.5

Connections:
+5V: PS1.3 (+VOUT); also elsewhere on the board
+12V: D6.2 (A); also elsewhere on the board
GND: PS1.2 (GND); also elsewhere on the board
unnamed: D6.1 (K), PS1.1 (+VIN)

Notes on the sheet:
逆接続保護ダイオード
Switching Regulator
From BUS
To MCU


Board: 2 copper layers, 90.0 x 70.0 mm, 84 parts (1 on the bottom side), 60 nets.

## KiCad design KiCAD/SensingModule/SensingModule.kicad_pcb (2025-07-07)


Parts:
D1, D2: Blue; LED_0603_1608Metric_Pad1.05x0.95mm_HandSolder
H5, H6, H7, H8: MountingHole_Pad; MountingHole_3.2mm_M3_DIN965_Pad_TopBottom
J1: DF11-8DP-2DS
J2: MONITOR; DF11-8DP-2DS; not fitted
R1, R2: 680R; R_0603_1608Metric_Pad0.98x0.95mm_HandSolder
R5, R6, R7, R8, R9, R17: 4.7kR; R_0603_1608Metric_Pad0.98x0.95mm_HandSolder
U1: ARDUINO_MKR_WAN_1310; BOARD_ARDUINO_MKR_WAN_1310; PARTREV 06/27/2019

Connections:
+3.3V: J2.1, R5.2, R6.2, R7.2, R8.2, R17.2, U1.J5_12 (+3V3); also elsewhere on the board
+3.3VP: R9.2; also elsewhere on the board
+5V: U1.J5_13 (VIN); also elsewhere on the board
+12V: J1.1, J1.2; also elsewhere on the board
CAN_H: J1.7, J1.8; also elsewhere on the board
CAN_L: J1.5, J1.6; also elsewhere on the board
CAN_RECEIVE_STATUS: U1.J3_9 (PA22/D0(PWM)); also elsewhere on the board
CAN_SEND_STATUS: U1.J3_10 (PA23/D1(PWM)); also elsewhere on the board
GND: D1.1 (K), D2.1 (K), J1.3, J1.4, J2.2, U1.J5_11 (GND); also elsewhere on the board
I2C_SCL: J2.4, R8.1, U1.J5_7 (PA09/D12(PWM)/SCL(SC2)); also elsewhere on the board
I2C_SDA: J2.3, R7.1, U1.J5_6 (PA08/D11/SDA(SC2)); also elsewhere on the board
LORA_RECEIVE_STATUS: R1.1, U1.J3_13 (PB10/D4(PWM))
LORA_SEND_STATUS: R2.1, U1.J3_14 (PB11/D5(PWM))
unnamed: D1.2 (A), R1.2
unnamed: D2.2 (A), R2.2
SPI_CS_MCP: R9.1, U1.J5_2 (PA21/D7(PWM)); also elsewhere on the board
SPI_MISO: U1.J5_5 (PA19/D10(PWM)/CIPO(SC1)); also elsewhere on the board
SPI_MOSI: U1.J5_3 (PA16/D8(PWM)/COPI(SC1)); also elsewhere on the board
SPI_SCLK: U1.J5_4 (PA17/D9/SCK(SC1)); also elsewhere on the board
SPI_~CS_FeRAM0: R6.1, U1.J5_9 (PB22/D14/TX(SC5)); also elsewhere on the board
SPI_~CS_FeRAM1: R5.1, U1.J3_4 (PB03/D17/AIN(11)/A2); also elsewhere on the board
SPI_~CS_FeRAM2: R17.1, U1.J5_8 (PB23/D13/RX(SC5)); also elsewhere on the board
VREF_T1: J2.5, U1.J3_5 (PA04/D18(PWM)/AIN(4)/A3)
VREF_T2: J2.6, U1.J3_6 (PA05/D19(PWM)/AIN(5)/A4)
VREF_T3: J2.7, U1.J3_7 (PA06/D20/AIN(6)/A5)
VREF_T4: J2.8, U1.J3_8 (PA07/D21/AIN(7)/A6)
VREF_THERMISTOR: U1.J3_2 (PA02/D15/DAC0/AIN(0)/A0); also elsewhere on the board

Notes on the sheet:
LoRa Status
M3 MoutHole


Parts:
C4, C5, C6: 0.1uF; C_0603_1608Metric_Pad1.08x0.95mm_HandSolder
C7, C8: 15pF; C_0603_1608Metric_Pad1.08x0.95mm_HandSolder
D5, D6: Blue; LED_0603_1608Metric_Pad1.05x0.95mm_HandSolder
R11: 120R; R_0603_1608Metric_Pad0.98x0.95mm_HandSolder
R12, R13: 680R; R_0603_1608Metric_Pad0.98x0.95mm_HandSolder
R14: 10kR; R_0603_1608Metric_Pad0.98x0.95mm_HandSolder
U4: MCP2515-xST; TSSOP-20_4.4x6.5mm_P0.65mm
U9: MCP2562-E-SN; SOIC-8_3.9x4.9mm_P1.27mm
Y1: 8MHz; Crystal_HC49-4H_Vertical

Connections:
+3.3VP: C5.2, C6.2, R14.2, U4.20 (VDD), U9.5 (Vio); also elsewhere on the board
+5V: C4.2, U9.3 (VDD); also elsewhere on the board
CAN_H: R11.1, U9.7 (CANH); also elsewhere on the board
CAN_L: R11.2, U9.6 (CANL); also elsewhere on the board
CAN_RECEIVE_STATUS: R12.1; also elsewhere on the board
CAN_RX: U4.2 (RXCAN), U9.4 (RXD)
CAN_SEND_STATUS: R13.1; also elsewhere on the board
CAN_TX: U4.1 (TXCAN), U9.1 (TXD)
GND: C4.1, C5.1, C6.1, C7.2, C8.2, D5.1 (K), D6.1 (K), U4.10 (VSS), U9.2 (VSS), U9.8 (STBY); also elsewhere on the board
unnamed: D5.2 (A), R12.2
unnamed: D6.2 (A), R13.2
unnamed: R14.1, U4.19 (~RESET)
OSC1: C7.1, U4.9 (OSC1), Y1.2
OSC2: C8.1, U4.8 (OSC2), Y1.1
SPI_CS_MCP: U4.18 (~CS); also elsewhere on the board
SPI_MISO: U4.17 (SO); also elsewhere on the board
SPI_MOSI: U4.16 (SI); also elsewhere on the board
SPI_SCLK: U4.14 (SCK); also elsewhere on the board

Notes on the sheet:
CAN Status
CAN トランシーバー
CAN コントローラー

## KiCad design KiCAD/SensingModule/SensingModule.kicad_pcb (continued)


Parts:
C1: 330uF; CP_Elec_10x10
C10, C11: 1uF; C_0805_2012Metric_Pad1.18x1.45mm_HandSolder
D3: Green; LED_0603_1608Metric_Pad1.05x0.95mm_HandSolder
D7: SS2040FL; D_SOD-123F
PS1: M78AR05-0.5; M78AR03305; Manufacturer_Part_Number M78AR05-0.5
R10: 2.2kR; R_0603_1608Metric_Pad0.98x0.95mm_HandSolder
U8: RT9080-33GJ5; TSOT-23-5

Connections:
+3.3VP: C11.1, U8.5 (OUT); also elsewhere on the board
+5V: C10.1, PS1.3 (+VOUT), U8.1 (IN), U8.3 (EN); also elsewhere on the board
+12V: C1.1, D7.2 (A), R10.1; also elsewhere on the board
GND: C1.2, C10.2, C11.2, D3.1 (K), PS1.2 (GND), U8.2 (GND); also elsewhere on the board
unnamed: D3.2 (A), R10.2
unnamed: D7.1 (K), PS1.1 (+VIN)

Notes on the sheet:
本当は RT9080-33GJ5
逆接続保護ダイオード
12V Status
From BUS
To MCU
Switching Regulator
Linear Regulator
From DCDC


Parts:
C14, C15, C16: 0.1uF; C_0603_1608Metric_Pad1.08x0.95mm_HandSolder
J3: DF51-2P-2DS
J4: DF51A-4P-2DS
R15: 10kR; R_0603_1608Metric_Pad0.98x0.95mm_HandSolder
U2: BNO055; AE-BNO055-BO
U5, U6, U7: MB85RQ8MX; SOIC-16W_7.5x10.3mm_P1.27mm
U14: SOIC-16W_7.5x10.3mm_P1.27mm; not fitted

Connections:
+3.3V: C14.1, C15.1, C16.1, J4.2, R15.1, U2.1 (VIN), U5.1 (~HOLD(IO3)), U5.2 (VDD), U5.9 (~WP(IO2)), U6.1 (~HOLD(IO3)), U6.2 (VDD), U6.9 (~WP(IO2)), U7.1 (~HOLD(IO3)), U7.2 (VDD), U7.9 (~WP(IO2)), U14.8 (WP(IO2)), U14.9 (HOLD(IO3)), U14.10 (VDD); also elsewhere on the board
GND: C14.2, C15.2, C16.2, J3.1, J4.1, U2.2 (GND), U2.7 (GND), U5.10 (VSS), U6.10 (VSS), U7.10 (VSS), U14.7 (VSS); also elsewhere on the board
I2C_SCL: J4.4, U2.4 (SCL/R); also elsewhere on the board
I2C_SDA: J4.3, U2.3 (SDA/T); also elsewhere on the board
SPI_MISO: U5.8 (SO(IO1)), U6.8 (SO(IO1)), U7.8 (SO(IO1)), U14.16 (SO(IO1)); also elsewhere on the board
SPI_MOSI: U5.15 (SI(IO0)), U6.15 (SI(IO0)), U7.15 (SI(IO0)), U14.2 (SI(IO0)); also elsewhere on the board
SPI_SCLK: U5.16 (SCK), U6.16 (SCK), U7.16 (SCK), U14.1 (SCK); also elsewhere on the board
SPI_~CS_FeRAM0: U5.7 (~CS); also elsewhere on the board
SPI_~CS_FeRAM1: U6.7 (~CS); also elsewhere on the board
SPI_~CS_FeRAM2: U7.7 (~CS); also elsewhere on the board
VREF_THERMISTOR: J3.2, R15.2; also elsewhere on the board

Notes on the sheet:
THERMISTOR
LPS28DFW
FeRAM1
BNO055
FeRAM2
FeRAM0
Thermistor



Board: 2 copper layers, 90.0 x 70.0 mm, 48 parts (23 on the bottom side), 32 nets.

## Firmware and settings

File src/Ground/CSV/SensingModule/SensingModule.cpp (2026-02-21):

/**
 * @file SensingModule.cpp
 * @brief 地上局（退避所）用のセンシングモジュールメインプログラム。
 * @details
 * このプログラムは、ロケットから送られてくる様々なセンサーデータ（加速度、高度、電力など）を
 * LoRa無線で受け取り、OLEDディスプレイに表示したり、パソコンにCSV形式で記録したりします。
 * ボタン操作で表示する情報を切り替えたり、ロケットにコマンドを送ったりすることもできます。
 * プログラムの動きを理解しやすいように、各部分の役割を詳しく説明しています。
 * @author H-62 Avionics Team
 * @date 2025-08-20
 */

// Arduinoの基本的な機能を使うための準備
#include <Arduino.h>
// SPI通信（センサーなどとデータをやり取りする方法）を使うための準備
#include <SPI.h>
// I2C通信（ディスプレイなどとデータをやり取りする方法）を使うための準備
#include <Wire.h>
// LoRa無線通信（遠くまでデータを送るための技術）を使うための準備
#include <LoRa.h>
// LoRaで送られてくるメッセージを分かりやすくするための準備
#include <MsgPacketizer.h>
// いろいろな処理を順番に、または同時に動かすための準備
#include <TaskManager.h>
// LoRa通信で使う基板の設定を読み込むための準備
#include "LoRaBoards.h"
// GPSのデータを簡単に扱えるようにするための準備
#include <TinyGPS++.h>
// ディスプレイに絵や文字を表示するための基本的な機能の準備
#include <Adafruit_GFX.h>
// 特定のOLEDディスプレイ（SSD1306）を動かすための準備
#include <Adafruit_SSD1306.h>

#define BUTTON_PIN 38                          ///< ボタンが接続されているArduinoのピン番号です。
const unsigned long LONG_PRESS_TIME_MS = 1000; ///< ボタンを「長押し」と判断する時間（ミリ秒）です。

Adafruit_SSD1306 display(128, 64, &Wire, -1); ///< ディスプレイを操作するための特別な「道具」です。
int currentPage = 0;                          ///< ディスプレイに表示する情報の「ページ番号」を覚えています。
const int NUM_PAGES = 9;                      ///< ディスプレイに表示できるページの全部の数です。

TinyGPSPlus onbordGps; ///< このロケットについているGPSからデータを受け取るための特別な「道具」です。

// --- 基準気圧設定 ---
uint32_t primaryPressure = 1014;   ///< 基準となる気圧（最初の気圧）を覚えています。
uint32_t secondaryPressure = 1014; ///< もう一つの基準となる気圧を覚えています。

// --- テレメトリーデータ ---
// ロケットから送られてくる様々なセンサーデータを一時的に保存しておくための変数たちです。
float telemetryRssi = 0.0;                   ///< LoRa無線でデータがどれくらいの強さで届いたか（電波の強さ）を示します。
float telemetrySnr = 0.0;                    ///< LoRa無線でデータがどれくらいきれいに届いたか（ノイズの少なさ）を示します。
float telemetryUptime = 0.0;                 ///< ロケットが動き始めてからどれくらいの時間が経ったか（秒）を示します。
char telemetryIdent = ' ';                   ///< ロケットの識別子（どのロケットからのデータか）を示します。
uint8_t telemetryLoggerUsage = 0;            ///< ロケットのデータ記録装置（ロガー）がどれくらい使われているか（%）を示します。
bool telemetryDoLogging = false;             ///< ロケットが今、データを記録中かどうか（はい/いいえ）を示します。
uint8_t telemetryFramNumber = 0;             ///< ロケットのデータ記録装置の番号を示します。
float telemetryAccelerationX = 0.0;          ///< ロケットのX方向の加速度（速さの変化）を示します。
float telemetryAccelerationY = 0.0;          ///< ロケットのY方向の加速度を示します。
float telemetryAccelerationZ = 0.0;          ///< ロケットのZ方向の加速度を示します。
float telemetryAccelerationNorm = 0.0;       ///< ロケットの全体の加速度の大きさを示します。
float telemetryRoll = 0.0;                   ///< ロケットのロール角（縦軸周りの回転）を示します。
float telemetryPitch = 0.0;                  ///< ロケットのピッチ角（横軸周りの回転）を示します。
float telemetryYaw = 0.0;                    ///< ロケットのヨー角（垂直軸周りの回転）を示します。
float telemetryForceX = 0.0;                 ///< ロケットのX方向にかかる力（推力など）を示します。
float telemetryJerkX = 0.0;                  ///< ロケットのX方向のジャーク（加速度の変化率）を示します。
float telemetryAltitude = 0.0;               ///< ロケットの現在の高度（地面からの高さ）を示します。
float telemetryVerticalSpeed = 0.0;          ///< ロケットの垂直方向の速さ（上昇・下降の速さ）を示します。
float telemetryEstimated = 0.0;              ///< ロケットの推定される何か（文脈による）を示します。
float telemetryApogee = 0.0;                 ///< ロケットが到達した最高高度を示します。
float telemetryExternalVoltage = 0.0;        ///< 外部電源の電圧を示します。
float telemetryBatteryVoltage = 0.0;         ///< バッテリーの電圧を示します。
float telemetryBusVoltage = 0.0;             ///< 内部の電力供給ライン（バス）の電圧を示します。
float telemetryExternalCurrent = 0.0;        ///< 外部電源の電流を示します。
float telemetryBatteryCurrent = 0.0;         ///< バッテリーの電流を示します。
float telemetryBusCurrent = 0.0;             ///< 内部の電力供給ラインの電流を示します。
float telemetryExternalPower = 0.0;          ///< 外部電源の電力（消費量）を示します。
float telemetryBatteryPower = 0.0;           ///< バッテリーの電力（消費量）を示します。
float telemetryBusPower = 0.0;               ///< 内部の電力供給ラインの電力（消費量）を示します。
float telemetryExternalDieTemperature = 0.0; ///< 外部の部品の温度を示します。
float telemetryBatteryDieTemperature = 0.0;  ///< バッテリーの部品の温度を示します。
float telemetryBusDieTemperature = 0.0;      ///< 内部の電力供給ラインの部品の温度を示します。

unsigned long buttonPressTime = 0; ///< ボタンが押され始めた時間を覚えています。
bool longPressSent = false;        ///< ボタンの長押しコマンドがもう送られたかどうか（はい/いいえ）を覚えています。

// --- 関数の宣言（これから作る関数の名前と、どんな情報を受け取るかを先に教えておく） ---
void updateDisplay();   // ディスプレイの表示を更新する関数
void sendLoRaCommand(); // LoRa無線でコマンドを送る関数
void loraRssiBar();     // LoRaの電波強度を棒グラフで表示する関数

/**
 * @brief LoRa無線でデータがどれくらいの強さで届いたか（電波の強さ）を棒グラフで表示します。
 * @details
 * この関数は、ロケットから送られてくる電波の強さ（RSSIという値）を測り、
 * その強さに応じてディスプレイに棒グラフ（アンテナのマークのようなもの）を描きます。
 * 電波が強いほど、棒がたくさん表示されます。
 * @note ディスプレイの右下に表示されます。
 */
void loraRssiBar()
{
    int rssi = LoRa.packetRssi(); // 今届いた電波の強さ（RSSI）を測ります。
    int bars = 0;                 // 表示する棒の数を数えるための変数です。
    // RSSIの値によって、表示する棒の数を決めます。
    if (rssi > -95.8)
        bars = 5; // 電波がとても強い
    else if (rssi > -101.6)
        bars = 4;
    else if (rssi > -107.4)
        bars = 3;
    else if (rssi > -113.2)
        bars = 2;
    else
        bars = 1; // 電波が弱い

    int barWidth = 5;   // 棒1本の幅です。
    int barSpacing = 1; // 棒と棒の間の隙間です。
    int barHeight = 8;  // 棒の高さです。
    // 棒グラフをディスプレイの右端に表示するための開始位置を計算します。
    int startX = 128 - (5 * (barWidth + barSpacing));
    int startY = 64 - barHeight; // 棒グラフをディスプレイの下端に表示するための開始位置を計算します。

    for (int i = 0; i < 5; i++)
    {
        // 棒の高さは、棒の番号（i）によって少しずつ変わります。
        int currentBarHeight = barHeight * (i + 1) / 5;
        // もし、今の棒の番号が表示するべき棒の数（bars）より小さければ、その棒を描きます。
        if (i < bars)
        {
            // ディスプレイに四角い棒を描きます。
            display.fillRect(startX + i * (barWidth + barSpacing), startY + (barHeight - currentBarHeight), barWidth, currentBarHeight, SSD1306_WHITE);
        }
    }
}

/**
 * @brief ディスプレイの各ページの共通のヘッダー（一番上の部分）を描画します。
 * @param[in] title これは、表示したいページの「タイトル」の文字です。
 *                  この関数は、このタイトルを使ってヘッダーを作りますが、
 *                  タイトル自体は変更しません。
 * @details
 * この関数は、ディスプレイの表示を一度全部消してから、
 * 今何ページ目を見ているか（P:ページ番号）、ページのタイトル、
 * そしてLoRaの電波強度を示す棒グラフを画面の一番上に表示します。
 */
void displayHeader(const char *title)
{
    display.clearDisplay();              // ディスプレイの表示を全部消します。
    display.setTextSize(1);              // 文字の大きさを一番小さいサイズに設定します。
    display.setTextColor(SSD1306_WHITE); // 文字の色を白に設定します。
    display.setCursor(0, 0);             // 文字を書き始める位置をディスプレイの左上（0,0）に設定します。
    display.print(F("P"));               // 「P」という文字を表示します。
    display.print(currentPage);          // 今のページ番号を表示します。
    display.print(F(":"));               // 「:」という文字を表示します。
    display.print(title);                // ページのタイトルを表示します。
    loraRssiBar();                       // LoRaの電波強度を示す棒グラフを表示します。
}

/**
 * @brief ページ0に「ステータス情報」を表示します。
 * @details
 * このページでは、LoRaの電波強度（RSSIとSNR）、ロケットが動いている時間（UPTIME）、
 * データ記録の状態（LOGとMEMORY）、そしてデータ記録装置の番号（FRAM）など、
 * ロケットの基本的な状態を一覧で確認できます。
 */
void displayPage0()
{
    displayHeader(" Status -");    // ページのヘッダーを「Status -」として表示します。
    display.setCursor(0, 10);      // 文字を書き始める位置を少し下にずらします。
    display.print(F("RSSI   : ")); // 「RSSI   : 」という文字を表示します。
    display.print(telemetryRssi);  // 受信したRSSIの値を表示します。
    display.println(F("dBm"));     // 「dBm」という単位を表示し、次の行に移ります。
    // 以下、同様に他のステータス情報を表示します。
    display.print(F("SNR    : "));
    display.print(telemetrySnr);
    display.println(F("dB"));
    display.print(F("UPTIME : "));
    display.print(telemetryUptime);
    display.println(F("s"));
    display.print(F("LOG    : "));
    display.println(telemetryDoLogging ? "ON" : "OFF"); // ロギング中なら「ON」、そうでなければ「OFF」を表示します。
    display.print(F("MEMORY : "));
    display.print(telemetryLoggerUsage);
    display.println(F("%"));
    display.print(F("FRAM: "));
    display.println(telemetryFramNumber);
    display.display(); // ディスプレイに実際に表示します。
}

/**
 * @brief ページ1に「高度情報」を表示します。
 * @details
 * このページでは、ロケットの現在の高度（ALT）、垂直方向の速さ（V/S）、
 * 最高高度（APO）
 * 高度に関する重要な情報を確認できます。
 */
void displayPage1()
{
    displayHeader(" Altitude -"); // ページのヘッダーを「Altitude -」として表示します。
    display.setCursor(0, 10);     // 文字を書き始める位置を少し下にずらします。
    display.print(F("ALT: "));
    display.print(telemetryAltitude);
    display.println(F("m"));
    display.print(F("V/S: "));
    display.print(telemetryVerticalSpeed);
    display.println(F("m/s"));
    display.print(F("APO: "));
    display.print(telemetryApogee);
    display.println(F("m"));
    display.display();
}

/**
 * @brief ページ2に「加速度情報」を表示します。
 * @details
 * このページでは、ロケットがどれくらいの速さで加速しているか（加速度）を、
 * X、Y、Zの3つの方向と、全体の大きさ（N）で確認できます。
 */
void displayPage2()
{
    displayHeader(" Accel [m/s2] -"); // ページのヘッダーを「Accel [m/s2] -」として表示します。
    display.setCursor(0, 10);         // 文字を書き始める位置を少し下にずらします。
    display.print(F("X: "));
    display.println(telemetryAccelerationX);
    display.print(F("Y: "));
    display.println(telemetryAccelerationY);
    display.print(F("Z: "));
    display.println(telemetryAccelerationZ);
    display.print(F("N: "));
    display.println(telemetryAccelerationNorm);
    display.display();
}

/**
 * @brief ページ3に「姿勢情報」を表示します。
 * @details
 * このページでは、ロケットがどの方向を向いているか（姿勢）を、
 * ロール、ピッチ、ヨーという3つの角度で確認できます。
 */
void displayPage3()
{
    displayHeader(" Orientation [deg] -"); // ページのヘッダーを「Orientation [deg] -」として表示します。
    display.setCursor(0, 10);              // 文字を書き始める位置を少し下にずらします。
    display.print(F("ROLL : "));
    display.println(telemetryRoll);
    display.print(F("PITCH: "));
    display.println(telemetryPitch);
    display.print(F("YAW  : "));
    display.println(telemetryYaw);
    display.display();
}

/**
 * @brief ページ4に「内部電力供給ライン（バス）の電力情報」を表示します。
 * @details
 * このページでは、ロケット内部の電子部品に電力を供給しているラインの電圧（V）、
 * 電流（I）、そして電力（P）を確認できます。
 */
void displayPage4()
{
    displayHeader(" Bus Power -"); // ページのヘッダーを「Bus Power -」として表示します。
    display.setCursor(0, 10);      // 文字を書き始める位置を少し下にずらします。
    display.print(F("V: "));
    display.print(telemetryBusVoltage);
    display.println(F(" V"));
    display.print(F("I: "));
    display.print(telemetryBusCurrent / 1000.0);
    display.println(F(" A"));
    display.print(F("P: "));
    display.print(telemetryBusPower);
    display.println(F(" W"));
    display.display();
}

/**
 * @brief ページ5に「バッテリーの電力情報」を表示します。
 * @details
 * このページでは、ロケットのバッテリーの電圧（V）、電流（I）、
 * そして電力（P）を確認できます。
 */
void displayPage5()
{
    displayHeader(" Battery Power -"); // ページのヘッダーを「Battery Power -」として表示します。
    display.setCursor(0, 10);
    display.print(F("V: "));
    display.print(telemetryBatteryVoltage);
    display.println(F(" V"));
    display.print(F("I: "));
    display.print(telemetryBatteryCurrent / 1000.0);
    display.println(F(" A"));
    display.print(F("P: "));
    display.print(telemetryBatteryPower);
    display.println(F(" W"));
    display.display();
}

/**
 * @brief ページ6に「外部電源の電力情報」を表示します。
 * @details
 * このページでは、ロケットに接続されている外部電源の電圧（V）、電流（I）、
 * そして電力（P）を確認できます。
 */
void displayPage6()
{
    displayHeader(" External Power -"); // ページのヘッダーを「External Power -」として表示します。
    display.setCursor(0, 10);
    display.print(F("V: "));
    display.print(telemetryExternalVoltage);
    display.println(F(" V"));
    display.print(F("I: "));
    display.print(telemetryExternalCurrent / 1000.0);
    display.println(F(" A"));
    display.print(F("P: "));
    display.print(telemetryExternalPower);
    display.println(F(" W"));
    display.display();
}

/**
 * @brief ページ7に「温度情報」を表示します。
 * @details
 * このページでは、ロケット内部の電子部品（バス、バッテリー、外部）の温度を
 * それぞれ確認できます。
 */
void displayPage7()
{
    displayHeader(" Temperature -"); // ページのヘッダーを「Temperature -」として表示します。
    display.setCursor(0, 10);
    display.print(F("BUS: "));
    display.print(telemetryBusDieTemperature);
    display.println(" C");

    display.print(F("BAT: "));
    display.print(telemetryBatteryDieTemperature);
    display.println(" C");

    display.print(F("EXT: "));
    display.print(telemetryExternalDieTemperature);
    display.println(" C");

    display.display();
}

/**
 * @brief ページ8に「ロケット搭載GPSの情報」を表示します。
 * @details
 * このページでは、ロケットに搭載されているGPSが取得した位置情報（緯度、経度）や
 * 捕捉している衛星の数を確認できます。もし有効なGPSデータがなければ、その旨を表示します。
 */
void displayPage8()
{
    displayHeader(" Onboard GPS -"); // ページのヘッダーを「Onboard GPS -」として表示します。
    display.setCursor(0, 10);
    // GPSデータが有効かどうかを確認します。
    if (onbordGps.location.isValid())
    {
        display.print(F("LAT: "));
        display.println(onbordGps.location.lat(), 6); // 緯度を表示します（小数点以下6桁まで）。
        display.print(F("LNG: "));
        display.println(onbordGps.location.lng(), 6); // 経度を表示します（小数点以下6桁まで）。
        display.print(F("SAT: "));
        display.println(onbordGps.satellites.value()); // 捕捉している衛星の数を表示します。
    }
    else
    {
        // 有効なGPSデータがないことを表示します。
        display.print(F("LAT: "));
        display.println("-.------");
        display.print(F("LNG: "));
        display.println("-.------");
        display.print(F("SAT: "));
        display.println("-");
    }
    display.display();
}

/**
 * @brief 現在のページ番号に応じて、対応する表示関数を呼び出し、ディスプレイを更新します。
 * @details
 * この関数は、`currentPage`という変数に保存されているページ番号を見て、
 * そのページに合った情報を表示する関数（例: `displayPage0()`など）を呼び出します。
 * これにより、ボタンを押すたびに表示内容が切り替わります。
 */
void updateDisplay()
{
    switch (currentPage) // 今のページ番号によって、どの表示関数を呼ぶか決めます。
    {
    case 0:
        displayPage0(); // ページ0なら、ステータス情報を表示します。
        break;
    case 1:
        displayPage1(); // ページ1なら、高度情報を表示します。
        break;
    case 2:
        displayPage2(); // ページ2なら、加速度情報を表示します。
        break;
    case 3:
        displayPage3(); // ページ3なら、姿勢情報を表示します。
        break;
    case 4:
        displayPage4(); // ページ4なら、バス電力情報を表示します。
        break;
    case 5:
        displayPage5(); // ページ5なら、バッテリー電力情報を表示します。
        break;
    case 6:
        displayPage6(); // ページ6なら、外部電力情報を表示します。
        break;
    case 7:
        displayPage7(); // ページ7なら、温度情報を表示します。
        break;
    case 8:
        displayPage8(); // ページ8なら、搭載GPS情報を表示します。
        break;
    }
}

/**
 * @brief ロケットに基準気圧設定コマンドをLoRa無線で送信します。
 * @details
 * この関数は、`primaryPressure`と`secondaryPressure`という変数に保存されている
 * 基準気圧の値を、LoRa無線を使ってロケットに送ります。
 * これにより、ロケットの気圧センサーの基準値を設定できます。
 */
void sendLoRaCommand()
{
    // 送信するメッセージ（パケット）を作成します。0xF4はコマンドの種類を示す番号です。
    const auto &packet = MsgPacketizer::encode(0xF4, primaryPressure, secondaryPressure);
    LoRa.beginPacket();                                 // LoRa無線での送信を開始します。
    LoRa.write(packet.data.data(), packet.data.size()); // 作成したメッセージをLoRa無線に乗せます。
    LoRa.endPacket();                                   // LoRa無線での送信を終了します。
}

/**
 * @brief ロケット搭載GPSのデータを定期的に更新するタスクです。
 * @details
 * この関数は、ロケット搭載GPSから送られてくる生データ（SerialGPS）を読み込み、
 * `onbordGps`という特別な道具を使って、緯度や経度などの分かりやすい情報に変換します。
 * もし今、GPS情報が表示されているページ（ページ8）であれば、ディスプレイも更新します。
 */
void taskGpsUpdate()
{
    // SerialGPSからデータが来る限り、読み込んでGPSデータを更新します。
    while (SerialGPS.available())
    {
        onbordGps.encode(SerialGPS.read()); // 1文字ずつ読み込んでGPSデータを解析します。
    }

    // もし今、GPS情報が表示されているページ（ページ8）であれば、ディスプレイを更新します。
    if (currentPage == 8)
    {
        updateDisplay();
    }
}

/**
 * @brief ボタンの状態をチェックし、短押し・長押しに応じた処理を行うタスクです。
 * @details
 * この関数は、ボタンが押されているかどうかを常に監視しています。
 * - **短押し**された場合：ディスプレイの表示ページを次のページに切り替えます。
 * - **長押し**された場合：ロケットに基準気圧設定コマンドをLoRa無線で送信します。
 */
void taskButtonCheck()
{
    bool buttonPressed = !digitalRead(BUTTON_PIN); // ボタンが押されているか（はい/いいえ）を調べます。

    if (buttonPressed) // もしボタンが押されていたら
    {
        if (buttonPressTime == 0) // 初めてボタンが押された瞬間なら
        {
            buttonPressTime = millis(); // 今の時間を記録します。
            longPressSent = false;      // 長押しコマンドはまだ送られていないことにします。
        }
        else if ((millis() - buttonPressTime > LONG_PRESS_TIME_MS) && !longPressSent) // 長押しと判断できる時間が経っていて、まだコマンドを送っていなければ
        {
            // 長押し時の動作

            sendLoRaCommand();    // LoRaコマンドを送ります。
            longPressSent = true; // 長押しコマンドは送られたことにします。
        }
    }
    else // もしボタンが押されていなかったら
    {
        if (buttonPressTime != 0 && !longPressSent) // ボタンが離された瞬間で、長押しではなかったら
        {
            // 短押し時の動作
            currentPage = (currentPage + 1) % NUM_PAGES; // ページ番号を1つ増やし、最後のページなら最初のページに戻ります。
            updateDisplay();                             // ディスプレイの表示を更新します。
        }
        buttonPressTime = 0; // ボタンが押され始めた時間をリセットします。
    }
}
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
void loop()
{
    Tasks.update(); // 登録されたタスクを動かします。

    // LoRa無線で新しいメッセージが届いていたら
    if (LoRa.parsePacket())
    {
        MsgPacketizer::parse(); // そのメッセージを解析し、対応する処理（setup関数で登録した処理）を実行します。
    }
}

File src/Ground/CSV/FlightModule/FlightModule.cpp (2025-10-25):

/**
 * @file FlightModule.cpp
 * @brief 地上局（退避所）用のフライトモジュールメインプログラム (AJAX対応Webサーバー版)
 * @details
 * T-Beamデバイス上で動作し、LoRa経由で受信したテレメトリーデータを処理する。
 * 機能一覧：
 * 1. OLEDディスプレイに受信データを表示する。
 * 2. シリアルポートにデータをCSV形式で出力する。
 * 3. Wi-Fiに接続し、受信データをモダンなUIのWebページで公開する。
 *    - Webページは初回ロード後、JavaScript(AJAX)で非同期にデータのみを更新するため、画面のちらつきやスクロールリセットが発生しない。
 * @author H-62 Avionics Team (modified by Gemini)
 * @date 2025-08-20
 */

#include <Arduino.h>
#include <SPI.h>
#include <Wire.h>
#include <LoRa.h>
#include <WiFi.h>
#include <ESPAsyncWebServer.h>
#include <MsgPacketizer.h>
#include <TaskManager.h>
#include <ArduinoJson.h>
#include "LoRaBoards.h"
#include <Adafruit_GFX.h>
#include <Adafruit_SSD1306.h>
#include <Lib_Var.hpp>
#include <TinyGPS++.h>

// --- Wi-Fi & Webサーバー設定 ---
const char *ssid = "SSID";
const char *password = "PASSWORD";
AsyncWebServer server(80);

// --- ハードウェア設定 ---
#define BUTTON_PIN 38
const unsigned long LONG_PRESS_TIME_MS = 1000;
Adafruit_SSD1306 display(128, 64, &Wire, -1);
int currentPage = 0;
const int NUM_PAGES = 5;
TinyGPSPlus onboardGps;

// --- 分離時間設定 ---
uint32_t separation1ProtectionTime = 22390;
uint32_t separation1ForceTime = 25390;
uint32_t separation2ProtectionTime = 84290;
uint32_t separation2ForceTime = 85290;
uint32_t landingTime = 88890;

// --- テレメトリーデータ (グローバル変数) ---
volatile float telemetryRssi = 0.0;
volatile float telemetrySnr = 0.0;
volatile char telemetryIdent = ' ';
volatile uint32_t telemetryMillis = 0;
volatile uint8_t telemetryFlightMode = 0;
volatile uint32_t telemetryFlightTime = 0;
volatile uint8_t telemetryLoggerUsage = 0;
volatile bool telemetryDoLogging = false;
volatile uint8_t telemetryFramNumber = 0;
volatile bool telemetryFlightPinIsOpen = false;
volatile bool telemetrySn3IsOn = false;
volatile bool telemetrySn4IsOn = false;
volatile bool telemetryIsLaunchMode = false;
volatile bool telemetryIsFalling = false;
volatile uint32_t telemetryUnixEpoch = 0;
volatile uint8_t telemetryFixType = 0;
volatile uint8_t telemetrySatelliteCount = 0;
volatile float telemetryLatitude = 0.0;
volatile float telemetryLongitude = 0.0;
volatile int16_t telemetryHeight = 0;
volatile int16_t telemetrySpeed = 0;
volatile uint16_t telemetryAccuracy = 0;
volatile float telemetryMotorTemperature = 0.0;
volatile float telemetryMcuTemperature = 0.0;
volatile float telemetryInputVoltage = 0.0;
volatile float telemetryCurrent = 0.0;
volatile float telemetryCurrentPosition = 0.0;
volatile float telemetryCurrentDesiredPosition = 0.0;
volatile float telemetryCurrentVelocity = 0.0;
volatile float telemetryMotorTemperature_SUPPLY = 0.0;
volatile float telemetryMcuTemperature_SUPPLY = 0.0;
volatile float telemetryInputVoltage_SUPPLY = 0.0;
volatile float telemetryCurrent_SUPPLY = 0.0;
volatile float telemetryCurrentPosition_SUPPLY = 0.0;
volatile float telemetryCurrentDesiredPosition_SUPPLY = 0.0;
volatile float telemetryCurrentVelocity_SUPPLY = 0.0;
volatile float telemetrySeparation1ProtectionTime = 0;
volatile float telemetrySeparation1ForceTime = 0;
volatile float telemetrySeparation2ProtectionTime = 0;
volatile float telemetrySeparation2ForceTime = 0;
volatile float telemetryLandingTime = 0;

unsigned long buttonPressTime = 0;
bool longPressSent = false;

// --- 関数プロトタイプ宣言 ---
void updateDisplay();
void sendLoRaCommand();
const char *getFlightModeString(uint8_t mode);
void handleRoot(AsyncWebServerRequest *request);
void handleData(AsyncWebServerRequest *request);

// --- Webページ生成ヘルパー関数 ---
String createStatusIndicator(const char *id, const char *label, bool isActive)
{
    String color = isActive ? "#28a745" : "#dc3545";
    String text = isActive ? "ON" : "OFF";
    return "<div class=\"status-item\">" + String(label) + ": <span id=\"" + String(id) + "_indicator\" class=\"indicator\" style=\"background-color:" + color + ";\"></span> <span id=\"" + String(id) + "_text\">" + text + "</span></div>";
}

String createProgressBar(const char *id, const char *label, int percentage)
{
    String html = "<div>" + String(label) + "</div>";
    html += "<div class=\"progress-bar\">";
    html += "<div id=\"" + String(id) + "\" class=\"progress-bar-inner\" style=\"width:" + String(percentage) + "%;\">" + String(percentage) + "%</div>";
    html += "</div>";
    return html;
}

// --- Webサーバーリクエストハンドラ ---
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

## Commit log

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2025-03-27 SubaruPlateのプロジェクトを開始
    [SubaruPlate.kicad_pcb, SubaruPlate.kicad_sch]
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2025-03-27 PowerModuleの作成開始
    [PowerModule.kicad_sch, PowerPlate.kicad_pcb, PowerPlate.kicad_sch]
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2025-03-28 SensingModule作業開始
    [CanInterface.kicad_sch, Peripheral.kicad_sch, Power.kicad_sch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]
2025-03-28 フライトモジュールのファイルを作成
    [FlightModule.kicad_pcb, FlightModule.kicad_sch]
2025-03-28 基板とArduinoの位置の決定
    [FlightModule.kicad_pcb, FlightModule.kicad_sch]
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2025-03-28 本日の進捗をコミット
    [FlightModule.kicad_sch]
2025-03-29 MB85RQ8MXを追加
    [FlightModule.kicad_sch]
2025-03-29 本日の進捗を保存
    [FlightModule.kicad_pcb, FlightModule.kicad_sch]
2025-04-04 基板の中に納めました
    [SensingModule.kicad_pcb, SensingModule.kicad_sch]
2025-04-04 基板とmkrの位置を中原さんのものに合わせました
    [CanInterface.kicad_sch, Peripheral.kicad_sch, Power.kicad_sch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]
2025-04-04 電池変更しました
    [PowerModule.kicad_pcb, PowerModule.kicad_sch]
2025-04-07 コネクタ以外は基板の中に入った
    [Peripheral.kicad_sch, SensingModule.kicad_pcb]
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2025-04-08 Sencingのフォルダー整理しました
    [CanInterface.kicad_sch, Peripheral.kicad_sch, Power.kicad_sch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]
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2025-04-08 大型の部品を配置
    [FlightModule.kicad_pcb, FlightModule.kicad_sch]
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2025-04-10 MKRGPSShield のKiCadファイルをアップロード 保存場所は要検討
    [MKRGPSShield_V4.0.kicad_pcb, MKRGPSShield_V4.0.kicad_sch]
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2025-04-12 Power, CanInterface, MCU, Sensorと項目に分け設計
    [CanInterface.kicad_sch, MicroController.kicad_sch, MicroControllerUnit.kicad_sch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]
2025-04-14 LTC3118の回路作ってみた
    [PowerModule.kicad_sch]
2025-04-14 PowerGood変更しました
    [PowerModule.kicad_sch]
2025-04-14 GPSSheildのフットプリントを救出
    [FlightModule.kicad_pcb, FlightModule.kicad_sch, MKRGPSShield_V4.0.kicad_pcb]
2025-04-14 GPSShieldのフットプリントをFlightModuleに移植（手作業☠️）
    [FlightModule.kicad_pcb, FlightModule.kicad_sch]
2025-04-14 配線をつなげようとしたがうまくいかず もう少し考えてみる
    [CanInterface.kicad_sch, Peripheral.kicad_sch, Power.kicad_sch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]
2025-04-15 MKRWAN問題解決
    [Power.kicad_sch, SensingModule.kicad_pcb, SensingModule.kicad_sch]
2025-04-17 BatteryModule追加＆電池設置
    [BatteryModule.kicad_pcb, BatteryModule.kicad_sch, PowerModule.kicad_pcb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]
2025-04-17 PowerModule基板に収まりました。配線検討中
    [PowerModule.kicad_pcb, PowerModule.kicad_sch]
2025-04-17 BNO、BME以外の配線を一応つなげた
    [SensingModule.kicad_pcb]
2025-04-20 SubaruPlateを更新
    [CanInterface.kicad_sch, MicroControllerUnit.kicad_sch, ServoMotor.kicad_sch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]
2025-04-20 ValveControlModuleを新規作成
    [CanInterface.kicad_sch, MicroControllerUnit.kicad_sch, Power.kicad_sch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]
2025-04-21 GPSShieldの配線の再現の途中
    [FlightModule.kicad_sch]
2025-04-21 ap2112k周りの配線を記載
    [FlightModule.kicad_sch]
2025-04-21 これ階層シートにしないとダメだな
    [FlightModule.kicad_sch]
2025-04-21 階層シート化した
    [FlightModule.kicad_sch, GPSShield.kicad_sch]
2025-04-21 コンデンサの容量耐圧が不明なため後ほど調べる
    [GPSShield.kicad_sch]
2025-04-23 配線作業終了、確認お願いします
    [Peripheral.kicad_sch, Power.kicad_sch, SensingModule.kicad_pcb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]
2025-04-24 配線できました。確認お願いします。
    [BatteryModule.kicad_pcb, BatteryModule.kicad_sch]
2025-04-24 MKR周りの配線完了
    [FlightModule.kicad_sch, GPSShield.kicad_sch]
2025-04-28 メモリ以外完成？
    [CanInterface.kicad_sch, FlightModule.kicad_sch, Peripheral.kicad_sch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]
2025-04-29 配線の確認お願いします
    [BatteryModule.kicad_pcb, PowerModule.kicad_pcb, PowerModule.kicad_sch]
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2025-04-30 Sensingの配線作業終わり、確認お願いします。
    [Peripheral.kicad_sch, Power.kicad_sch, SensingModule.kicad_pcb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]
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2025-04-30 電源，RS485の仕様を確定
    [MicroControllerUnit.kicad_sch, Power.kicad_sch, ServoMotor.kicad_sch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]
2025-05-01 基本的な機能が完成
    [MicroControllerUnit.kicad_sch, ValveControlModule.kicad_pcb]
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2025-05-02 GNDが繋がらない件です。確認お願いします
    [SensingModule.kicad_pcb]
2025-05-02 BatteryModuleの外形完成
    [BatteryModule.kicad_pcb, BatteryModule.kicad_sch]
2025-05-02 GPSShieldの部分完了
    [GPSShield.kicad_sch]
2025-05-04 CANトランシーバーの配線完了
    [CanInterface.kicad_sch, FlightModule.kicad_pcb, FlightModule.kicad_sch]
2025-05-04 CANコントローラーの回路図完成
    [CanInterface.kicad_sch]
2025-05-04 バスの回路図完成，LEDの配置を変更
    [CanInterface.kicad_sch, FlightModule.kicad_sch]
2025-05-04 分離周りの回路図完成
    [Separation.kicad_sch]
2025-05-04 M85RQ8MX の回路図完成
    [Peripheral.kicad_sch]
2025-05-04 DCDCコンバーターを交換，3.3Vレギュレーターを配置
    [Power.kicad_sch]
2025-05-04 GNSSモジュール，SAM-M8Qの回路図完成
    [GPSShield.kicad_sch]
2025-05-04 回路図8割完成
    [FlightModule.kicad_sch, GPSShield.kicad_sch]
2025-05-04 配線8割り終わり．次の作業....
    [CanInterface.kicad_sch, FlightModule.kicad_pcb, FlightModule.kicad_sch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]
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2025-05-04 ステータスLEDの表示まで完了
    [FlightModule.kicad_pcb]
2025-05-05 後は最終確認
    [CanInterface.kicad_sch, MicroControllerUnit.kicad_sch, Power.kicad_sch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]
2025-05-05 残りは最終確認
    [ValveControlModule.kicad_pcb]
2025-05-05 エラー０！！
    [BatteryModule.kicad_pcb]
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2025-05-05 dxfを追加．KiCADにインポートすれば基板外形を作成できる．
    [StandardBoard.dxf, SubaruPlate.dxf]
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2025-05-05 FeRAMを3個に増設
    [FlightModule.kicad_pcb, FlightModule.kicad_sch, Peripheral.kicad_sch]
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2025-05-08 配線完了
    [BatteryModule.kicad_pcb, PowerModule.kicad_pcb, PowerModule.kicad_sch]
2025-05-08 配線確認お願いします
    [Peripheral.kicad_sch, Power.kicad_sch, SensingModule.kicad_pcb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]
2025-05-08 簡単な警告を修正
    [Peripheral.kicad_sch, SensingModule.kicad_pcb, SensingModule.kicad_sch]
2025-05-08 塗りつぶしとクリアランスの設定を変更．エラーは無し．
    [PowerModule.kicad_pcb]
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2025-06-18 電源系統図を修正
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2025-06-19 再度修正
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2025-06-21 MOSFETのフットプリントを修正
    [PowerControl.kicad_sch, PowerControlModule.kicad_pcb]
2025-06-21 MOSFET周りのフットプリント，回路図を修正
    [ServoMotor.kicad_sch]
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2025-07-07 修正した．発注する．
    [CanInterface.kicad_sch, Power.kicad_sch, SensingModule.kicad_pcb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]
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2025-07-08 何を修正したか忘れてしまった．
    [18650BatteryModule.kicad_pcb, BatteryModule.kicad_pcb, FlightModule.kicad_pcb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]
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2025-07-21 場所ずれていたので修正
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2025-08-02 テレメトリー周りを修正中
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2025-08-14 FlightTimeの型を修正
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2025-11-06 バグ修正
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2026-02-21 修正したライブラリを実装
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2026-02-21 バグっていたので修正
